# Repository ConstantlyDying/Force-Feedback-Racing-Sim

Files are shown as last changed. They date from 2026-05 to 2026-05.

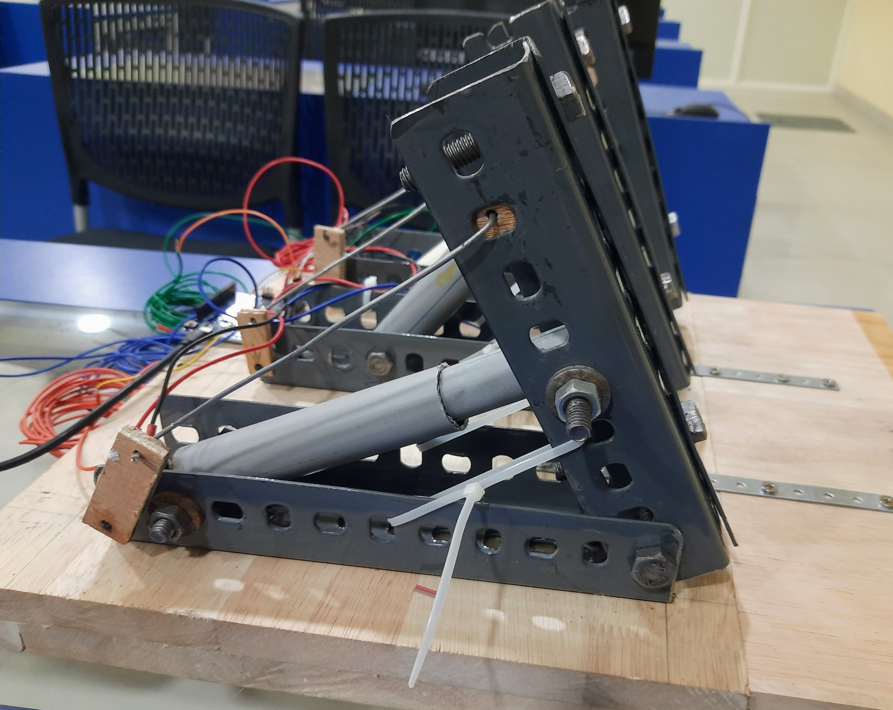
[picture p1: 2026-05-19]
Build Media/Pictures/Pedals/20260518_082918.jpg

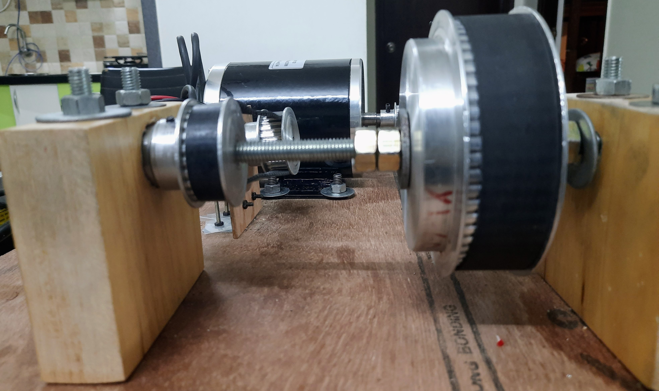
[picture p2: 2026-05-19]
Build Media/Pictures/Wheel Base/20260515_222247.jpg

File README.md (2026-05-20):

# Force-Feedback-Racing-Sim
A budget friendly - DIY Racing simulator, powered by an Arduino Leonardo and a beefy 500w motor!!

FFB Racing Sim2

I made this as a budget friendly alternative to popular sim wheels:), and when your doing this stuff DIY, the possibilities are endless!!, you can literally slap on Wind Sim, Rev Lights, Speedometer, H-shifter, rumble pedals and literally whatever you can think of!!

# Pedals
image_2026-05-05_010524761-Photoroom

These are the pedals. Whenever a certain pedal is pressed; its corresponding potentiometer underoges rotation and sends that analog signal to the Arduino, and communicates with the sim/game.

## -IRL Build


I didn't add the plates as there was enough area on the pedals to apply force onto them without it. You can add the plates if needed though:)

# Wheel-Base
image_2026-05-05_010300429-Photoroom

Pretty straightforward. You rotate the Steering Wheel, the encoder reads the movement and sends it to the Arduino, which communicates it to the sim/game, and sends back a signal to the motor drivers, which induces a movement in the motors accordingly and moves the wheel. There you go, Force Feedback!!

## -IRL Build


I've used one motor driver as that is able to handle my motor load well. You can add one more if you feel the driver is heating up a lot.

# Schematics


FYI: I've custom made the symbols for Arduino, BTS7960, and the Rotary Encoder:)

# Firmware


I've used EMC Lite, which is a popular firmware among the SIM Racing community. Obviously, you can use any other firmware depending on your microcontroller (I'm using an 8bit Arduino Leonardo). This firmware has all the essentials for providing proper Force Feedback, supports 3 pedals, and can handle upto 16 switches with a leonardo. You can definitely add on functionality by using other softwares like SimHub in addition to this for more immersiveness (such as: adding wind sim or rev lights).

# Step-By-Step Build Guide
Yep!! a fully detailed build guide :))



Head to [Detailed Build Guide](https://github.com/ConstantlyDying/Force-Feedback-Racing-Sim/tree/main/Detailed%20Build%20Guide) to access it!

# Demo
https://youtu.be/QV2LuhKqWK8

# BOM
|SR. No: |Name: |Quantity:|Unit Price: (INR) |Total Price:(INR)|Unit Price: (USD) |Total Price:(USD)|Link: |Merchant |Description |
|---|---|---|---|---|---|---|---|---|---|
|STEERING WHEEL:| | | | | | | | | |
| |ELECTRONICS: | | | | | | | | |
|1 |24V 500W 2500RPM MY1020 EBIKE Brush Motor |1 |₹4,400.00 |₹4,400.00 |$46.11 |$46.11 |https://robu.in/product/500w-24v-dc-2500-rpm-for-scooter-bike-go-kart-minibike-e-atv-my1020/ |Self Sourced|A DC motor to drive the wheel |
|2 |Double BTS7960 43A H-Bridge High-Power Stepper Motor Driver|1 |₹300.00 |₹300.00 |$3.14 |$3.14 |https://robu.in/product/double-bts7960-43a-h-bridge-high-power-stepper-motor-driver-module/ |Self Sourced|The motor driver for controlling the motor |
|3 |Arduino Leonardo R3 Board |1 |₹500.00 |₹500.00 |$5.24 |$5.24 |https://robu.in/product/arduino-leonardo-r3-board-micro-usb/ |Self Sourced|Microcontroller for running the firmware and integrating all components|
|4 |1000 PPR AB 2-Phase Optical Rotary Encoder |1 |₹2,500.00 |₹2,500.00 |$26.20 |$26.20 |https://robu.in/product/orange-1000-ppr-ab-phase-incremental-optical-rotary-encoder/ |Self Sourced|Rotary encoder for detecting turns in the steering wheel |
|5 |24VOLT 41AMP 1000WAT SMPS |1 |₹6,000.00 |₹6,000.00 |$62.87 |$62.87 |https://tridevpowersupply.com/product/my-tridev-24volt-41amp-1000wat-switching-power-supply-universal-regulated-transformer-ac-110v-220v-to-dc-24v-41a|Self Sourced|Main power supply to power up everything |
|6 |Cooling fans - 24V |2 |₹150.00 |₹300.00 |$1.57 |$3.14 |https://robu.in/product/a423-fs4020x24v-brushless-dc-cooling-fan-with-2pin-cable-for-3d-printer/ |Self Sourced|Cooling fans to dissipate heat from motor driver |
| |HARDWARE: | | | | | | | | |
|7 |Threaded Metal rod (10mm) |1 |₹150.00 |₹150.00 |$1.57 |$1.57 |Sourced locally |Self Sourced|For the steering shaft |
|8 |Steering Wheel |1 |₹2,500.00 |₹2,500.00 |$26.20 |$26.20 |https://www.amazon.in/AUTO-MT-Tractor-13INCH-Steering/dp/B0B7BLK5XZ/ref=sr_1_2 |Self Sourced|Reduces rpm of motor and provides more torque in a 1:4 ratio |
|9 |big timing pulley (XXL-60teeth) |1 |All pulleys with belt costed 7500| |All pulleys with belt costed $78.80| |Sourced locally |Self Sourced| |
|10 |small timing pulley(XXL-15teeth) |1 | | | | |Sourced locally |Self Sourced| |
|11 |medium timing pulley(XL-22 teeth) |2 | | | | |Sourced locally |Self Sourced|Detects rotation of steering by connecting to encoder in a 1:1 ratio |
|12 |timing belt(XL) |1 | | | | |Sourced locally |Self Sourced|Connects the pulleys |
|13 |timing belt (XXL) |1 | | | | |Sourced locally |Self Sourced| |
|14 |bearings (25mm OD, 10mm ID) |2 |₹150.00 |₹300.00 |$1.57 |$3.14 |Sourced locally |Self Sourced|Helps the motor shaft move more smoothly |
|15 |Nuts (m10) |10 |₹10.00 |₹100.00 |$0.10 |$1.00 |Sourced locally |Self Sourced|For fastening |
|16 |Self drill screws |12 |₹5.00 |₹60.00 |$0.05 |$0.60 |Sourced locally |Self Sourced|For fastening |
|17 |Wood Mount for steering shaft (10*9cm) |2 | | | |$0.00 |Sourced locally |Self Sourced|The shaft goes here along with the bearings |
|18 |Wood Base (40*65cm) |1 | | | |$0.00 |Sourced locally |Self Sourced|Wooden base of the wheel base, for mounting everything |
|19 |Nuts and Bolts (M8) |10 |₹20.00 |₹200.00 |$0.21 |$2.10 |Sourced locally |Self Sourced|for fastening everything |
|PEDALS: | | | | | | | | | |
|20 |10k rotary potentiometer |3 |₹30.00 |₹90.00 |$0.31 |$0.93 |https://robu.in/product/10k-ohm-3pin-15mm-shaft-potentiometer-pack-of-3/ |Self Sourced|For detecting intensity of pedal press |
|21 |spring |3 |₹200.00 |₹600.00 |$2.10 |$6.30 |Sourced locally |Self Sourced|Gives resistance in the pedals |
|22 |Metal L brackets (19cm) |6 |₹150.00 |₹900.00 |$1.57 |$9.42 |Sourced locally |Self Sourced|For a rigid pedal frame |
|23 |Metal L brackets set (22cm) |6 |₹150.00 |₹900.00 |$1.57 |$9.42 |Sourced locally |Self Sourced| |
|24 |Nuts and Bolts (m8) |18 |₹20.00 |₹360.00 |$0.21 |$3.78 |Sourced locally |Self Sourced|To fasten everything |
|25 |Nuts and bolts set (m10) |3 |₹20.00 |₹60.00 |$0.21 |$0.63 |Sourced locally |Self Sourced| |
|26 |Self drill screws |10 |₹5.00 |₹50.00 |$0.05 |$0.50 |Sourced locally |Self Sourced| |
|27 |pvc pipe (3/4inch) |3 |₹10.00 |₹30.00 |$0.10 |$0.30 |Sourced locally |Self Sourced|Springs are housed inside this |
|28 |pvc pipe (1inch) |3 |₹10.00 |₹30.00 |$0.10 |$0.30 |Sourced locally |Self Sourced| |
|29 |Machining Costs |1 |₹600.00 |₹600.00 |$6.29 |$6.29 |Sourced locally |Self Sourced|Machining, such as cutting the wood and metal pieces |
|30 |Wood base (30*36cm) |1 | | | | |Sourced locally |Self Sourced|Wooden Base for mounting the pedals. |

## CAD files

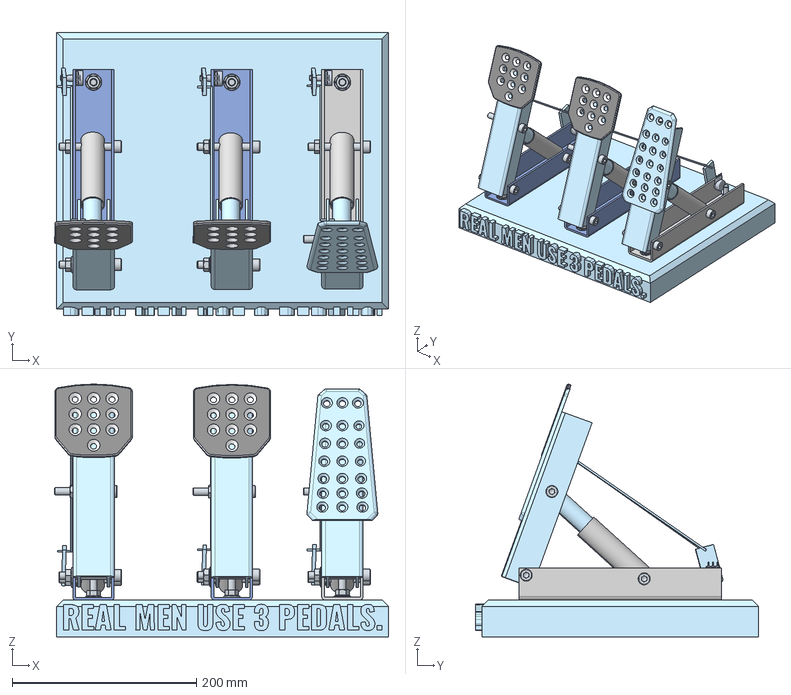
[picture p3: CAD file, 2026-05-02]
CAD (as step file)/Fully Assembled/Pedals/PEDALS MAIN.step
362.3 x 307.0 x 274.3 mm
Hex flange nut M8x1.25 x 15
Surface 1 x 3
Hex socket head cap screw M8x1.25 x 50 x 6
Fanatec_CSP-V3 v8 x 2
Hex socket head cap screw M8x1.25 x 60 x 9
id114 x 3
id119 x 3
id124 x 3
id129 x 3
id134 x 3
id139 x 3
id144 x 3
id149 x 3

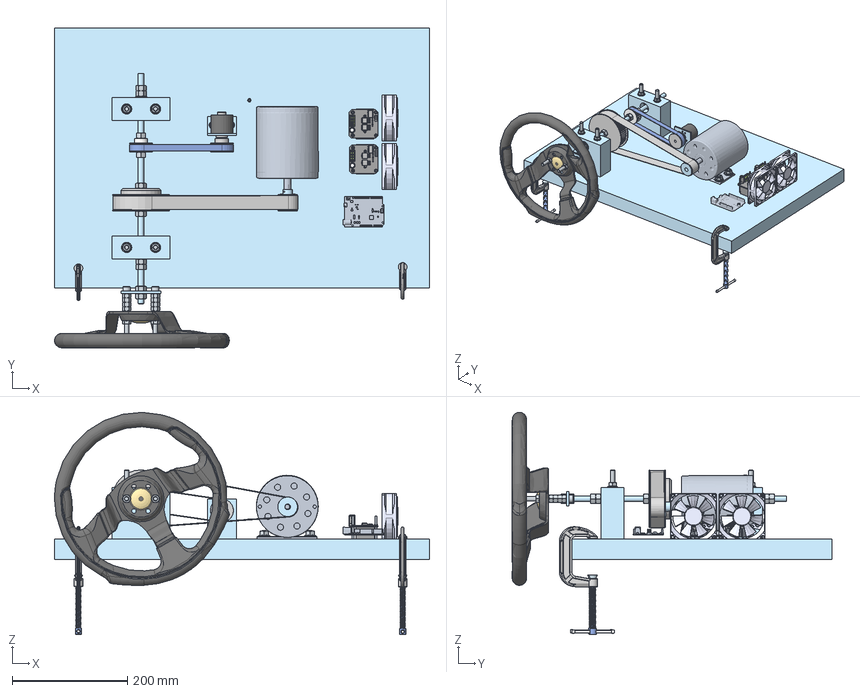
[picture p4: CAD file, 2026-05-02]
CAD (as step file)/Fully Assembled/Wheel Base/WHEEL BASE MAIN.step
650.1 x 554.0 x 385.5 mm
Hex flange nut M10x1.50 x 4
Hex nut grade A & B M3x0.5 x 10
Hex socket head cap screw M6x1.00 x 35 x 2
Fan x 8
4668K121_Permanently Lubricated Stainless Steel Ball Bearing x 10
Hex nut grade A & B M10x1.5 x 10
Hex nut grade A & B M8x1.25 x 12
Hex socket head cap screw M3x0.50 x 60 x 18 x 8
Coil x 20
Spur gear (22 teeth) x 2
Chamfered plain washer normal M10 x 2
id124
id129
id134
ROTARY ENCODER rohit v1 x 2
Hex socket head cap screw M8x1.25 x 140 x 4
Hex flange nut M8x1.25 x 6
Hex socket head cap screw M8x1.25 x 35 x 4
id199 x 2
id204 x 2
id209 x 2
id214 x 2
id219 x 2
id224 x 2
id229 x 2
id234 x 2
id239 x 2
id244 x 2
Fan Body x 2
Hex socket head cap screw M8x1.25 x 80 x 2
id285
Hex flange nut M6x1.00 x 2
steering wheel 300mm
COMBINE2 x 2
CUT-EXTRUDE6 x 2
SOJ 20_001 x 18
2Pos Terminal Block_002 x 10
Capacitor_001 x 16
0805 Resistor_005 x 2
2Pos Terminal Block_001 x 10
2x4 Male Header_001 x 2
M2.5x6-Screw x 4
BTN7960_001 x 2
0805 Resistor_001 x 2
0805 Resistor_002 x 2
0805 Resistor_007 x 2
0805 Resistor_008 x 2
0805 Resistor_004 x 2
0805 Resistor_006 x 2
BTN7960_002 x 2
0805 Resistor_003 x 2
Spur gear (60 teeth)

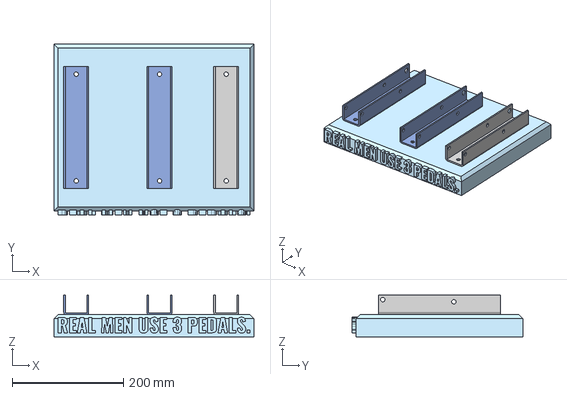
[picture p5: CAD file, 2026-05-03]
CAD (as step file)/Parts/Pedals/pedal base.step
360.0 x 307.0 x 75.0 mm

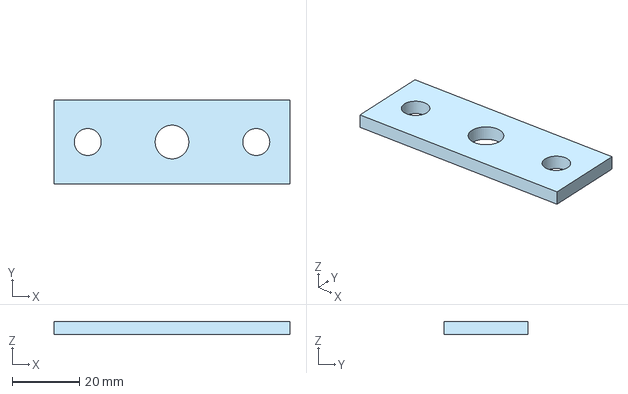
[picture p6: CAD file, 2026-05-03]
CAD (as step file)/Parts/Wheel Base/steering mount.step
70.0 x 25.0 x 4.00 mm

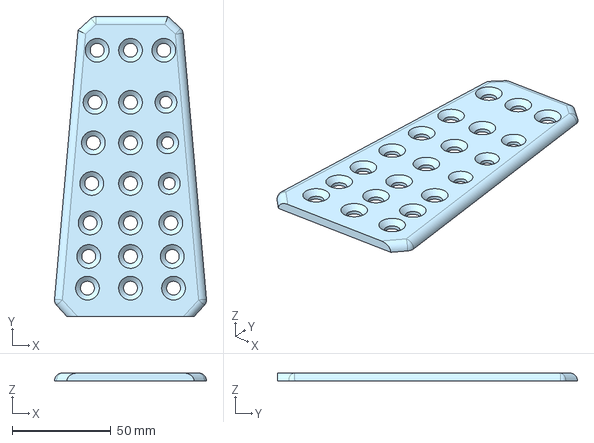
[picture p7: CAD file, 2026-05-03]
CAD (as step file)/Parts/Pedals/Accelerator.step
76.9 x 151.7 x 4.00 mm

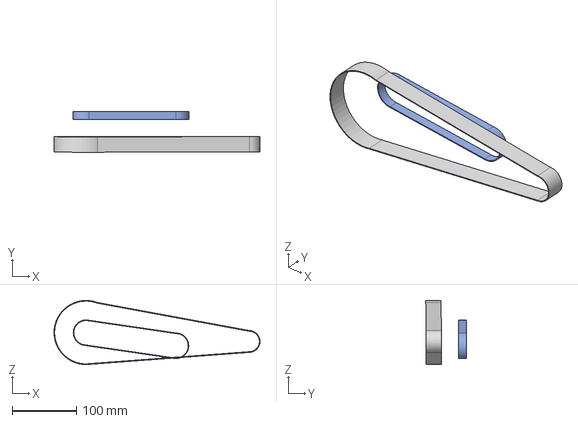
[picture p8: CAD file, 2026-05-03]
CAD (as step file)/Parts/Wheel Base/wheel base.step
321.2 x 63.2 x 100.2 mm

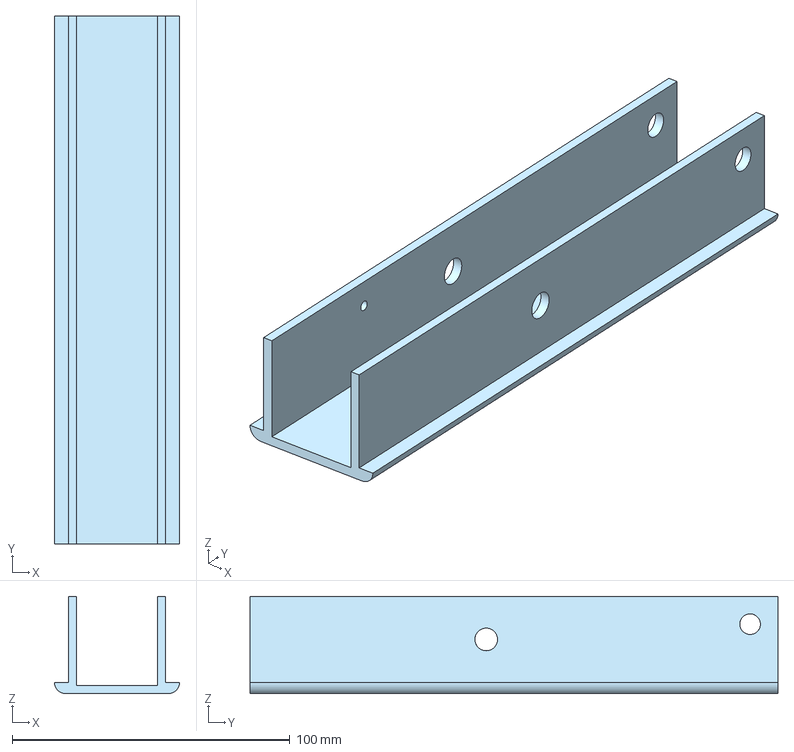
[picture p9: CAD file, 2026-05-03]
CAD (as step file)/Parts/Pedals/upper pedal.step
45.0 x 190.0 x 35.0 mm

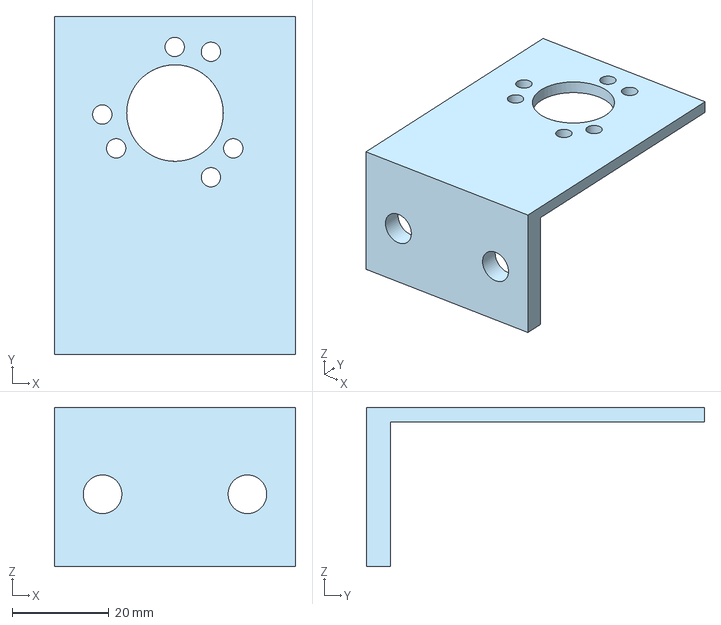
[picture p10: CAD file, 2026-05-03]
CAD (as step file)/Parts/Wheel Base/encoder mount.step
50.0 x 70.0 x 33.0 mm

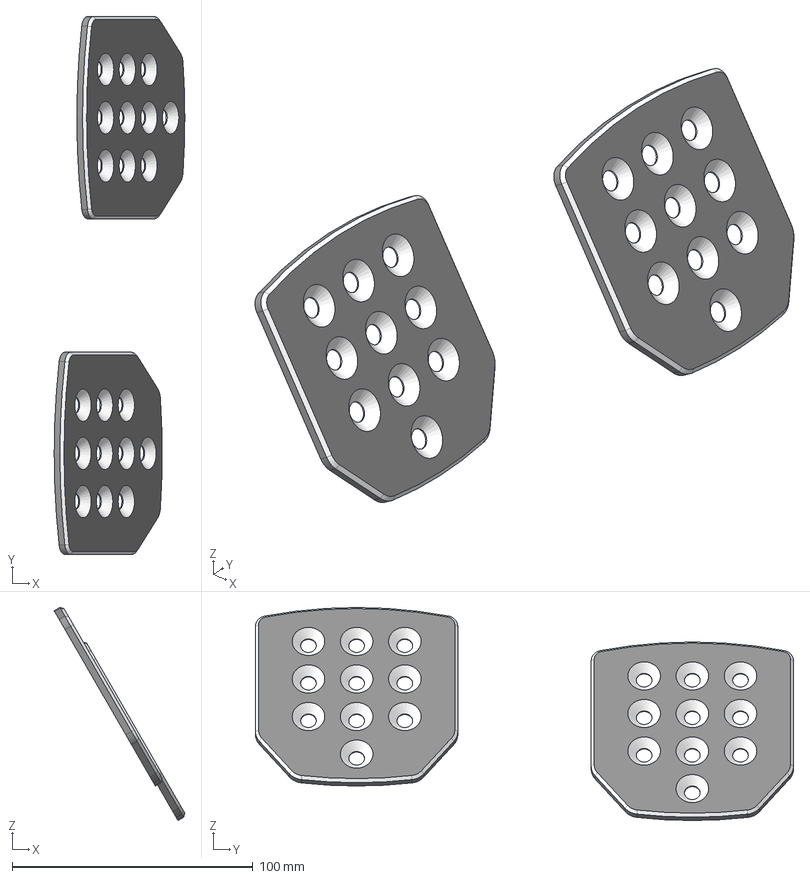
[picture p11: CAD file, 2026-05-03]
CAD (as step file)/Parts/Pedals/pedal plates.step
54.2 x 223.4 x 88.5 mm
Fanatec_CSP-V3 v8 x 2

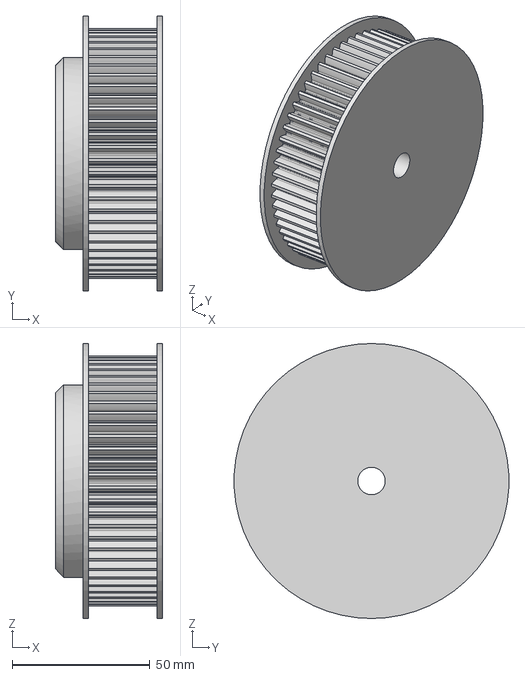
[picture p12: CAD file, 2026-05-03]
CAD (as step file)/Parts/Wheel Base/60 teeth pulley.step
39.0 x 99.9 x 100.0 mm

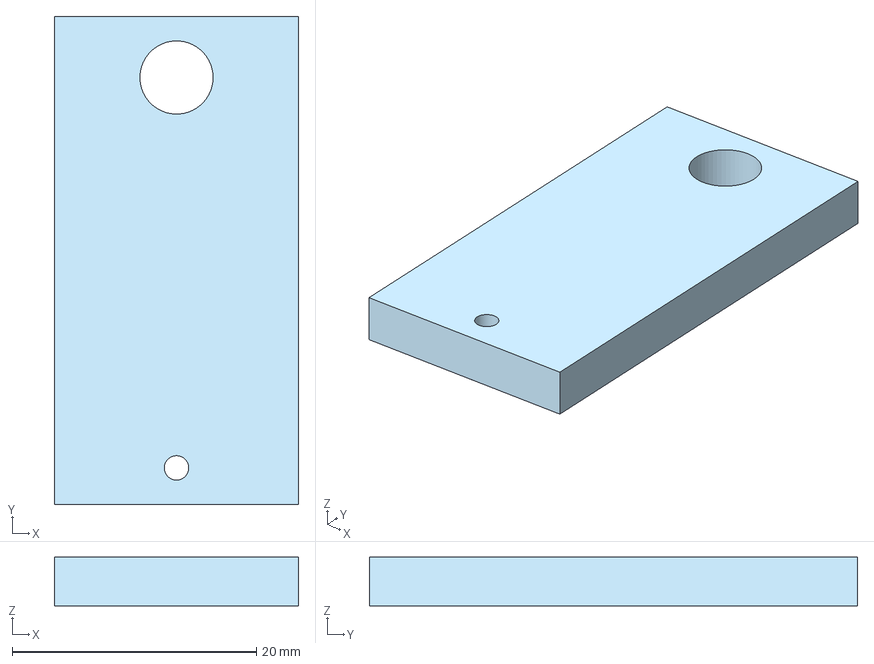
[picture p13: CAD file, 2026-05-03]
CAD (as step file)/Parts/Pedals/wooden rectangle.step
20.0 x 40.0 x 4.00 mm

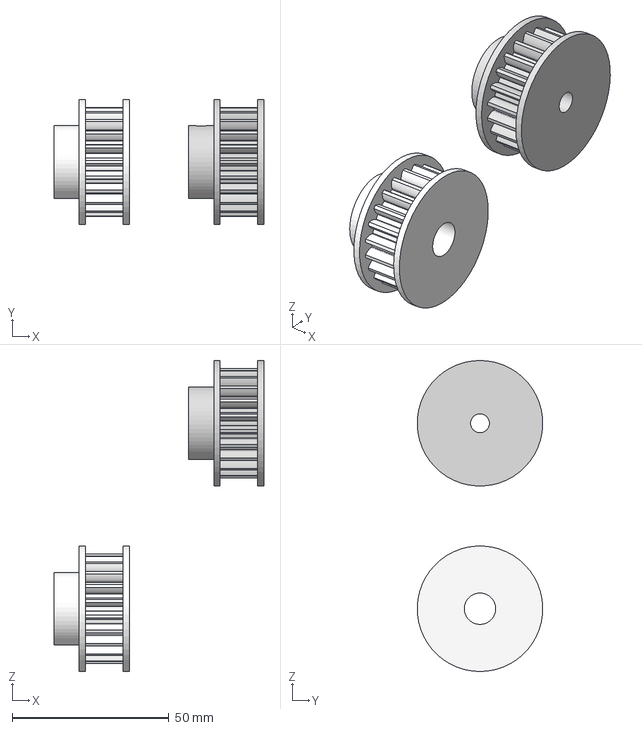
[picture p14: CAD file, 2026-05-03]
CAD (as step file)/Parts/Wheel Base/22 teeth pulleys.step
66.9 x 40.0 x 99.1 mm

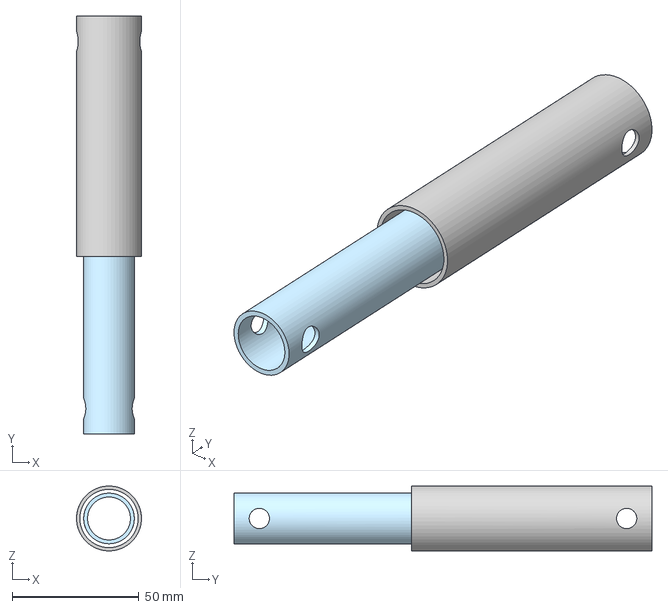
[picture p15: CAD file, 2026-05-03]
CAD (as step file)/Parts/Pedals/pipes.step
25.6 x 165.0 x 25.6 mm

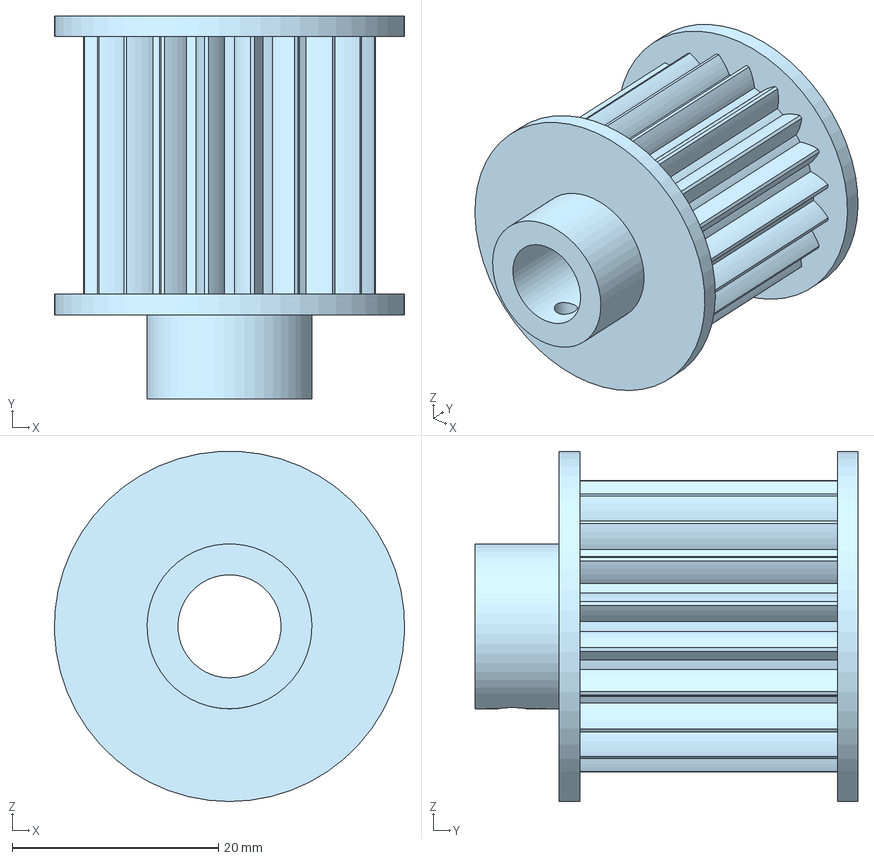
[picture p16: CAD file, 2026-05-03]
CAD (as step file)/Parts/Wheel Base/Motor pulley.step
34.0 x 37.2 x 34.0 mm

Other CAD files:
CAD (as step file)/Parts/Pedals/push rod.step
CAD (as step file)/Parts/Wheel Base/bearings.step
CAD (as step file)/Parts/Pedals/potentiometer.step
CAD (as step file)/Parts/Wheel Base/threaded rod.step

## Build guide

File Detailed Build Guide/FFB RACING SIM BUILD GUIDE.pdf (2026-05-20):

## FFB RACING SIM -BUILD GUIDE:

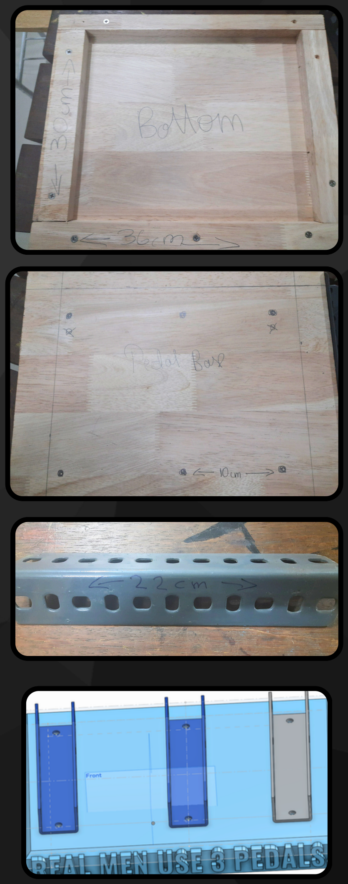
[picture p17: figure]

## PEDALS:

Get your wooden base of dimension 36cm by 30cm (if you are
anchoring it somewhere), or 36cm by 45cm if you are not anchoring it.
Add 4 beams of about 3cm width to each edge.
With the help of 22cm L-Bracket, mark 3 sets oh holes on the base for each pedal. (10cm b/w the brake and gas pedal ; 17cm b/w the brake and the clutch).
Now drill the holes with an 8mm drill bit.
Take 2 of the 22cm L-Brackets and overlap them, to for a U-Shape, now mount them on the base with m8 nuts and bolts.
Repeat the previous step thrice.

## NOTE:

This is just a guide, you are free to change the dimensions or components if you like, provided you know what you are doing.
Every step does not need to be exact, a close enough replication works, as lot of the stuff I used were sourced locally:)

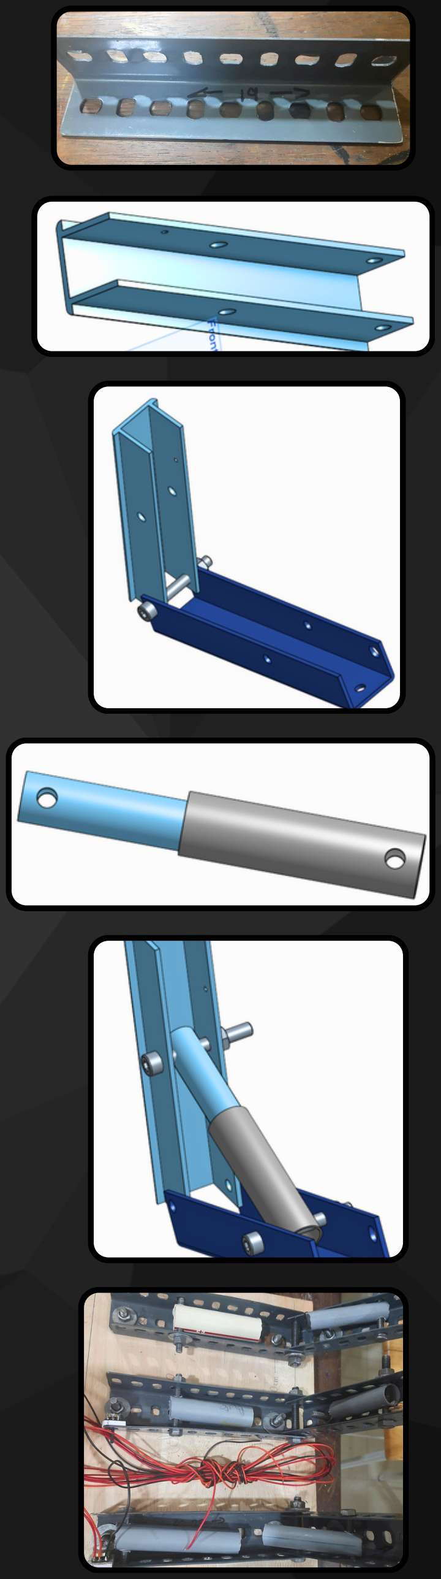
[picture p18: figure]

Take 2 of the 19cm L-Brackets and overlap them to form a U-shape and fasten them together with m8 nuts and bolts.
Now join the upper pedal to the base with m10 nuts and bolts. You can use a pair of pliers to bend the base L-Bracket outwards if needed.
Take out your ¾ inch and 1 inch pvc pipes and cut them to 10cm each(3pcs for each dia), this length depends on your spring, I am using a 4inch one. It also depends on how much pressure you want to apply on the pedals, so definitely feel free to
customize.
Now drill out one hole through each pipe with an 8mm drill bit. Now take the 1inch pipes and mount them to the base L-Bracket with m8 nuts and bolts, and do the same for the ¾ inch pipes, but to the upper pedal.
Repeat this step thrice.
Now use epoxy to make a seal on the other end of each ¾ inch pipe.
Once that dries, take out your spring and put it in the 1inch pipe.
Now use the ¾ inch pipe to enclose the spring, and use zipties or something to limit the pedals movement so the springs don’t come out.

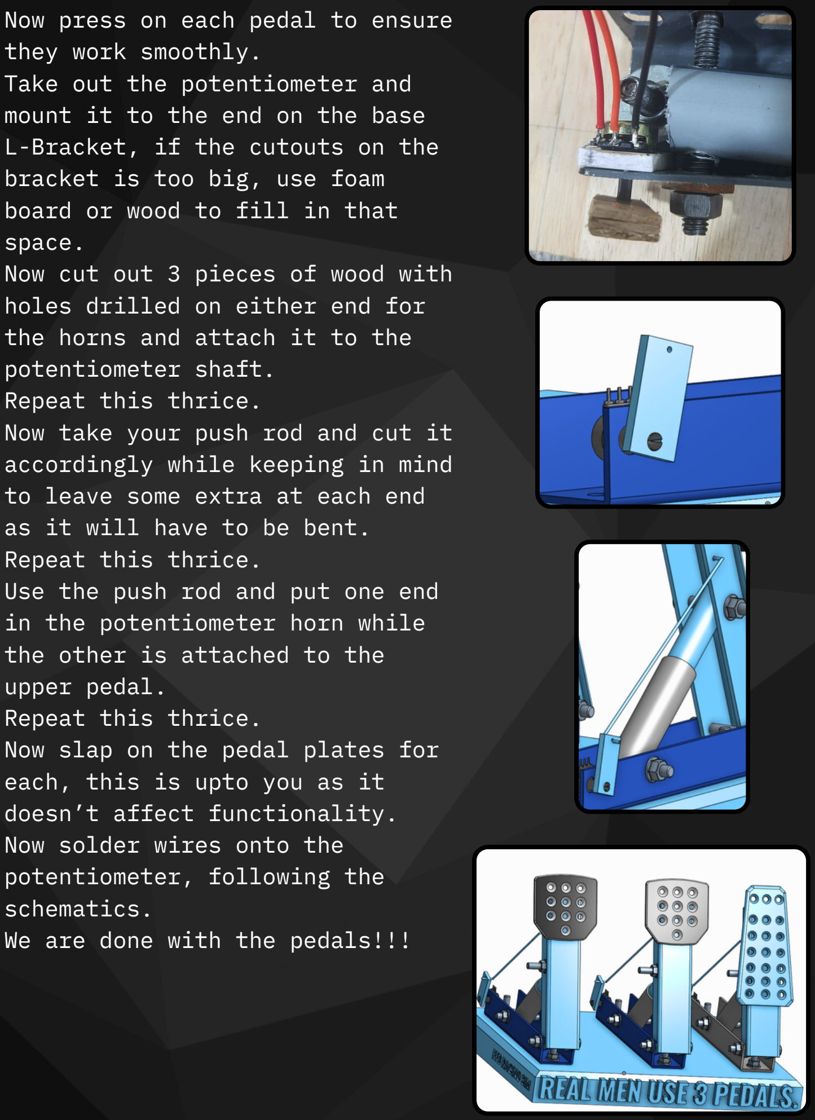
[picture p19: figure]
Now press on each pedal to ensure they work smoothly. Take out the potentiometer and mount it to the end on the base L-Bracket, if the cutouts on the bracket is too big, use foam board or wood to fill in that space. Now cut out 3 pieces of wood with holes drilled on either end for the horns and attach it to the potentiometer shaft. Repeat this thrice. Now take your push rod and cut it accordingly while keeping in mind to leave some extra at each end as it will have to be bent. Repeat this thrice. Use the push rod and put one end in the potentiometer horn while the other is attached to the up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

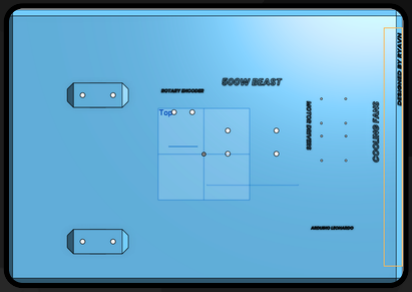
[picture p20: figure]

## Wheel-base:

Take a wooden base of dimension 40cm*65cm
Take the wooden steering shaft mount of dimensions 9*10cm with the bearing mounted in it.
Drill 2 holes in the wooden mount through out with an 8mm drill bit.
Now with the help of the
steering shaft mount, mark 2 holes about 7 to 8cm away from the long edge (please refer to the onshape link or cad file for a better understanding).
Now with the help of the same mount, mark 2 more holes about 24 to 25cm away from the previous holes.
Now drill these holes with an 8mm drill bit.
Mount one steering shaft mount to the holes closer to the edge with m8 nuts and bolts.
Now insert the threaded rod into the bearing and position the 2 steering shaft mount on the other set of holes, but don’t mount it yet.

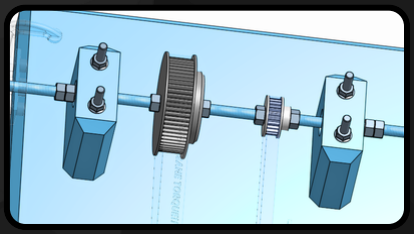
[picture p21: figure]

nd

Now Take out the 60 teeth and 22 teeth pulleys and fasten them to the threaded rod as shown in the CAD. Ensure they are properly secured with m10 bolts.

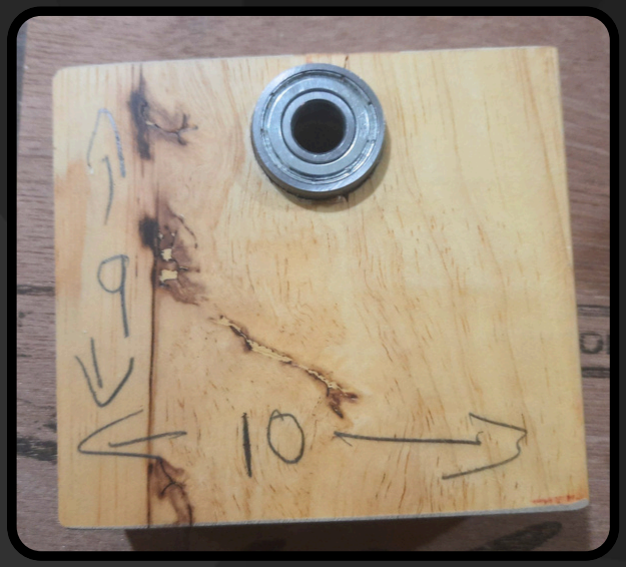
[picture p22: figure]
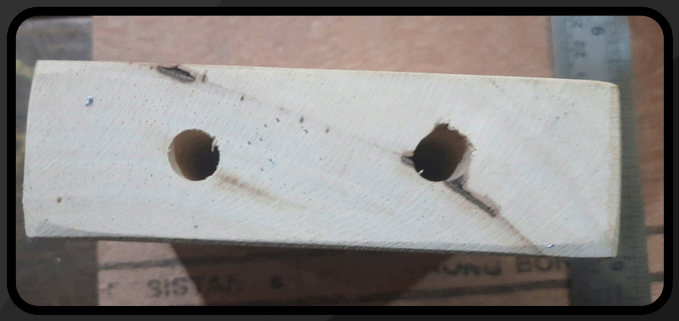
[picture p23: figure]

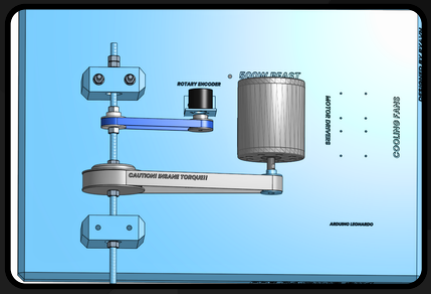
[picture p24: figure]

Now insert both the pulleys’ belts onto the rod.
Mount the other steering shaft mount with m8 nuts and bolts. Take out your motor and encoder (with mount).
Mount the 15teeth pulley onto the motor shaft.
Use the longer timing belt by positioning it on the 60 and 20 teeth pulleys and mark 4 holes for mounting the motor (ensuring the belt is tight and fits snug on the pulleys), ensure these holes are offset to the direction away from the threaded rod by about 0.5cm to induce tension in the belt.
Do the same with the rotary encoder and mark 2 holes.
Now drill out all these holes with an 8mm drill bit.
Mount the rotary encoder and motor to their mount holes accordingly with m8 nuts and bolts.
If the belt doesn’t have enough tension, or is too tight (please refer to yt tutorial on checking belt tension), shift the
corresponding pulley a bit on the threaded rod, and drill the mount holes again, but a bit closer to the shaft.
Now make the steering mount, I used a rectangular metal piece and drilled 3 holes: one 10mm one in the center and

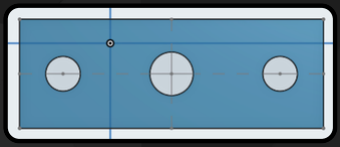
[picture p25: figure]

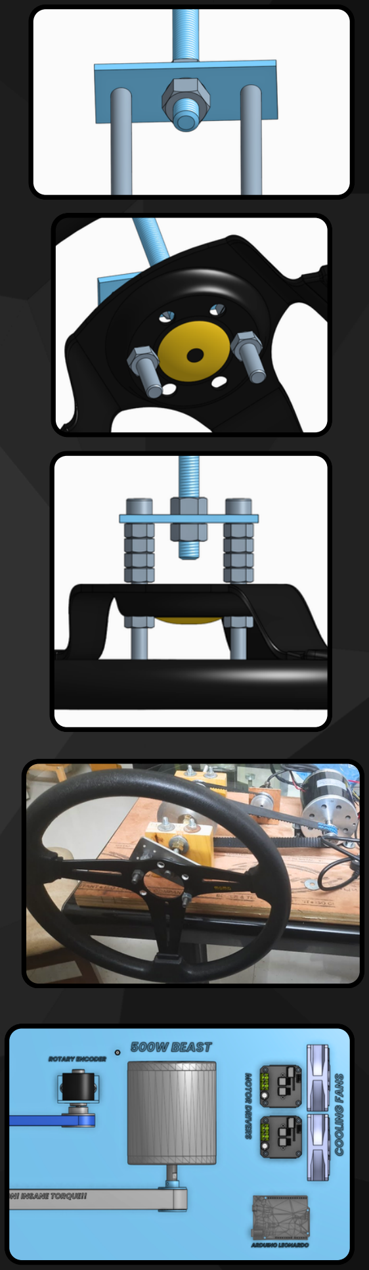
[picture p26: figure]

Now make the steering mount, I used a rectangular metal piece and drilled 3 holes: one 10mm one in the center and two 8mm ones equidistant from the center on both the sides (This depends on your steering wheel).
Now push the center hole onto the steering shaft (threaded rod) and use m10 nuts on either side to fasten it.
Insert two m8 bolts and use a few nuts to act as spacers.
Now mount your steering wheel onto these two m8 bolts and fasten it with m8 nuts.
Give the wheel a spin to check if it moves smoothly:)
Now take both of your motor drivers and position it near the motor.
Now mark out the mount holes for the motor driver, and drill them out with a 4mm drill bit
Mount them with m4 nuts and bolts.
Now take the cooling fans and position it near the heatsinks of the motor driver, you can now glue them in place or use L-Brackets to mount them
accordingly.
Now take your Arduino Leonardo and position it a bit below the motor driver and mark out 4 holes.
Drill the holes with a 4mm drill bit and mount in with a set of m4 nusts

Drill the holes with a 4mm drill bit and mount it with m4 nuts and bolts. You can also use glue! The position of the Arduino, Motor driver and the cooling fans aren’t that crucial, as long as the wiring is neat and they have proper ventilation:)
Now wire them up according to the schematics.
You have officially finished the Wheel Base!!!

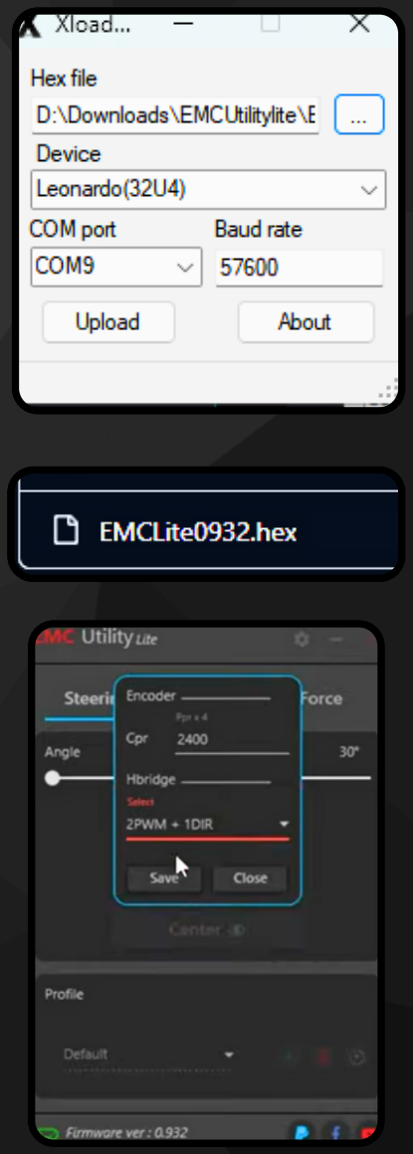
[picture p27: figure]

## Configuring:

Download all the required files from my GitHub Repo.
Connect your Arduino to your PC, and open Xloader.
Select the downloaded hex file from my repo, leonardo as the device.
Now short the reset and GND pins briefly on the leonardo and remove, this will show a new COM port, which you have to select. Now upload the firmware.
Now open settings, and set the cpr value to your ppr value*4, mine is 1000 so cpr = 4000 and save it.
Now go to the pedals tab for calibration: Keep a pedal pressed down entirely, and click max; now let go of it and click min. Repeat this thrice.

Download all the required files from my GitHub Repo.
Connect your Arduino to your PC, and open Xloader.
Select the downloaded hex file from my repo, leonardo as the device.
Now short the reset and GND pins briefly on the leonardo and remove, this will show a new COM port, which you have to select. Now upload the firmware.
Now open settings, and set the cpr value to your ppr value*4, mine is 1000 so cpr = 4000 and save it.
Now go to the pedals tab for calibration: Keep a pedal pressed down entirely, and click max; now let go of it and click min. Repeat this thrice.
Now go to the main page, now center your steering wheel physically and click center wheel.
You can set the max degree of rotation for the steering wheel depending on your game/sim.
You can also go to the force tab and play around with the
settings, till you find it comfortable.

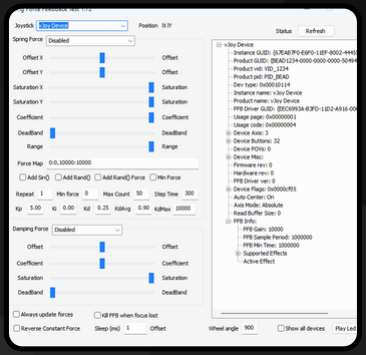
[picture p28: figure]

You must always keep the EMC app open when running the wheel. Select EMC for joystick.
You can use the Wheel Check software to test if the wheel is running smoothly.
You can open any compatible game/sim and connect the
controller like any other
wheel:).
Calibrate all the axes and buttons and you’re good to go!! You’ve officially completed the build!!!!

## Testing:

# -BY Ryaan Ahmed:)

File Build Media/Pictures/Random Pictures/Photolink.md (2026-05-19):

https://photos.app.goo.gl/hW5AqJL3e2coWAPn7

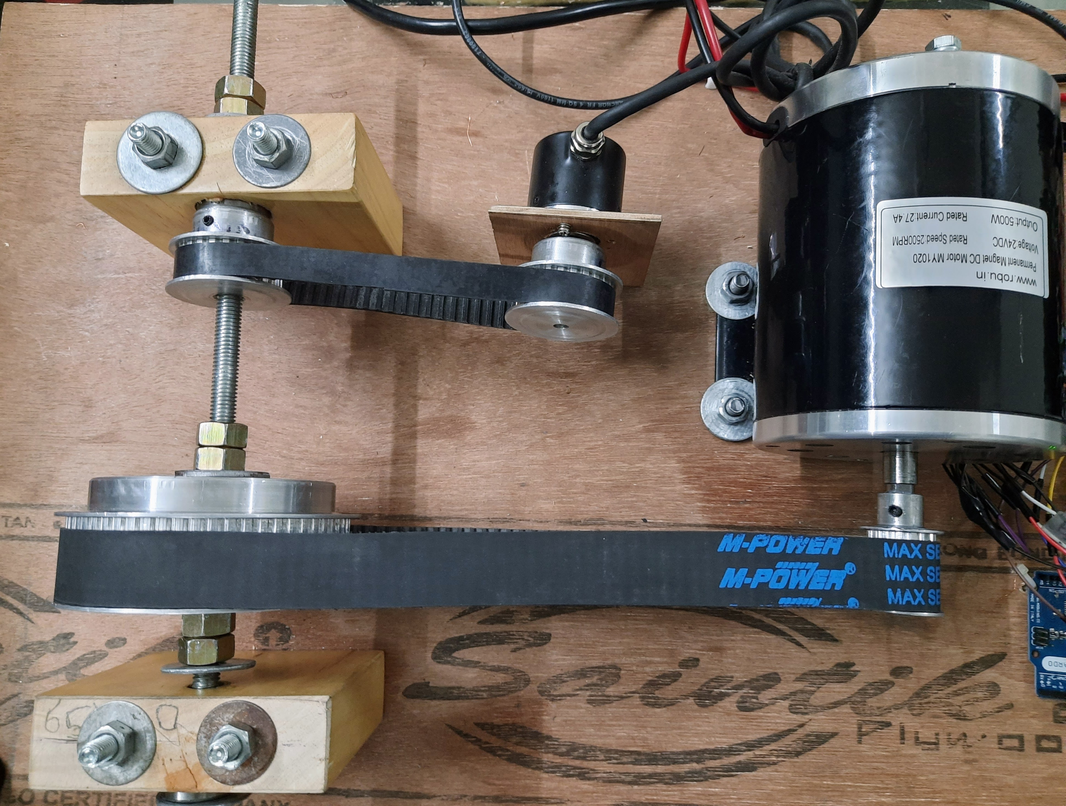
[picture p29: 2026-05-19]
Build Media/Pictures/Wheel Base/20260515_222138.jpg

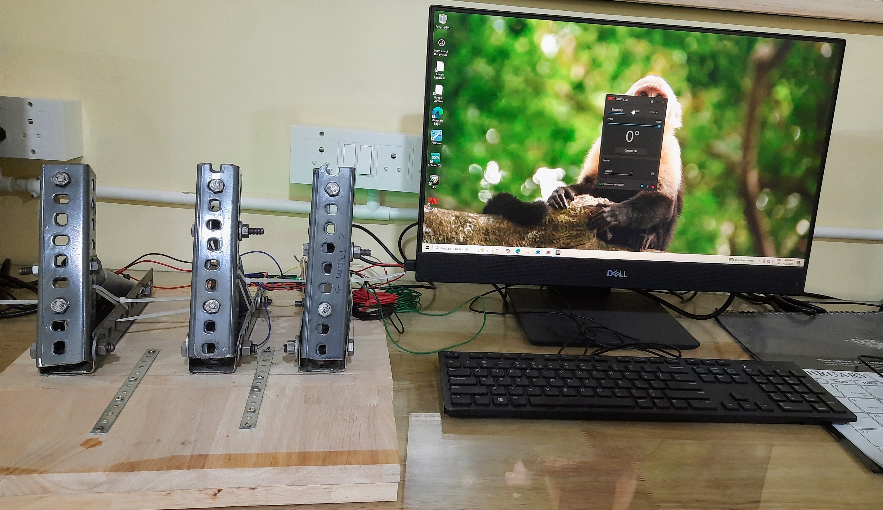
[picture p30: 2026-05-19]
Build Media/Pictures/Pedals/20260518_082357.jpg

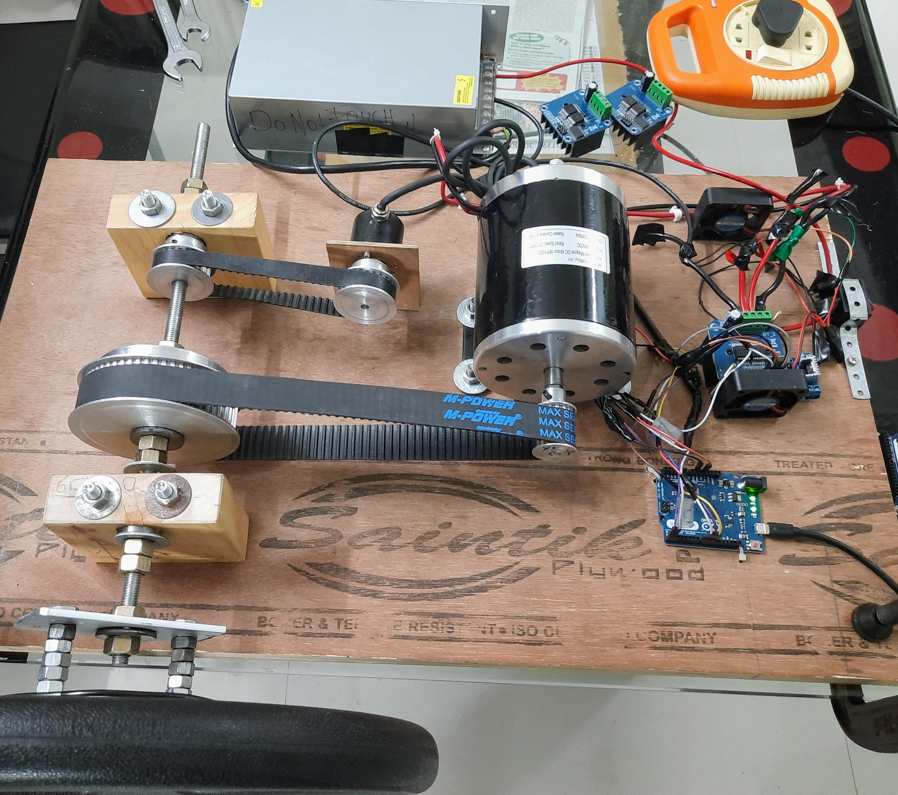
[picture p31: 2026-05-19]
Build Media/Pictures/Wheel Base/20260515_222124.jpg

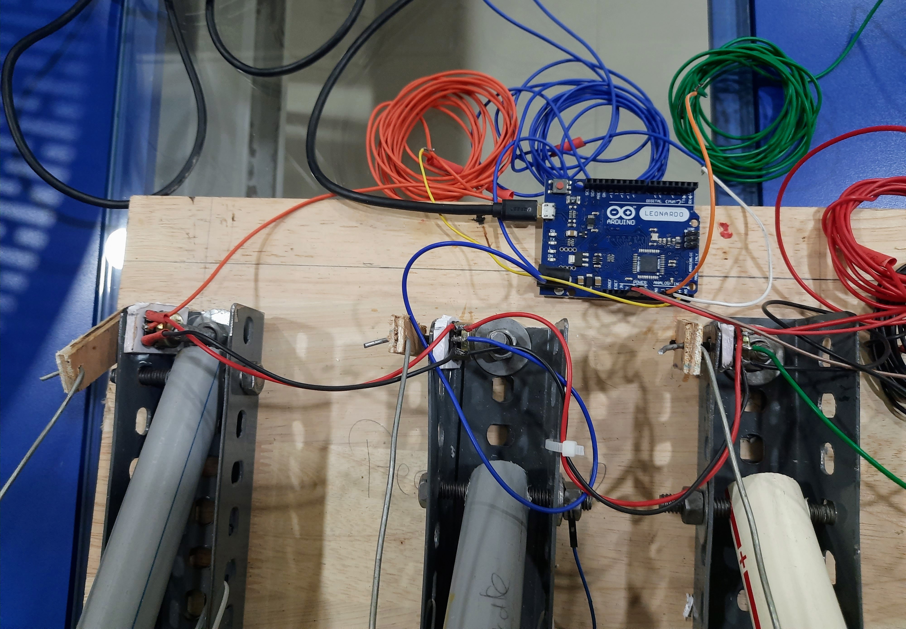
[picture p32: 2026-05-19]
Build Media/Pictures/Pedals/20260518_082927.jpg

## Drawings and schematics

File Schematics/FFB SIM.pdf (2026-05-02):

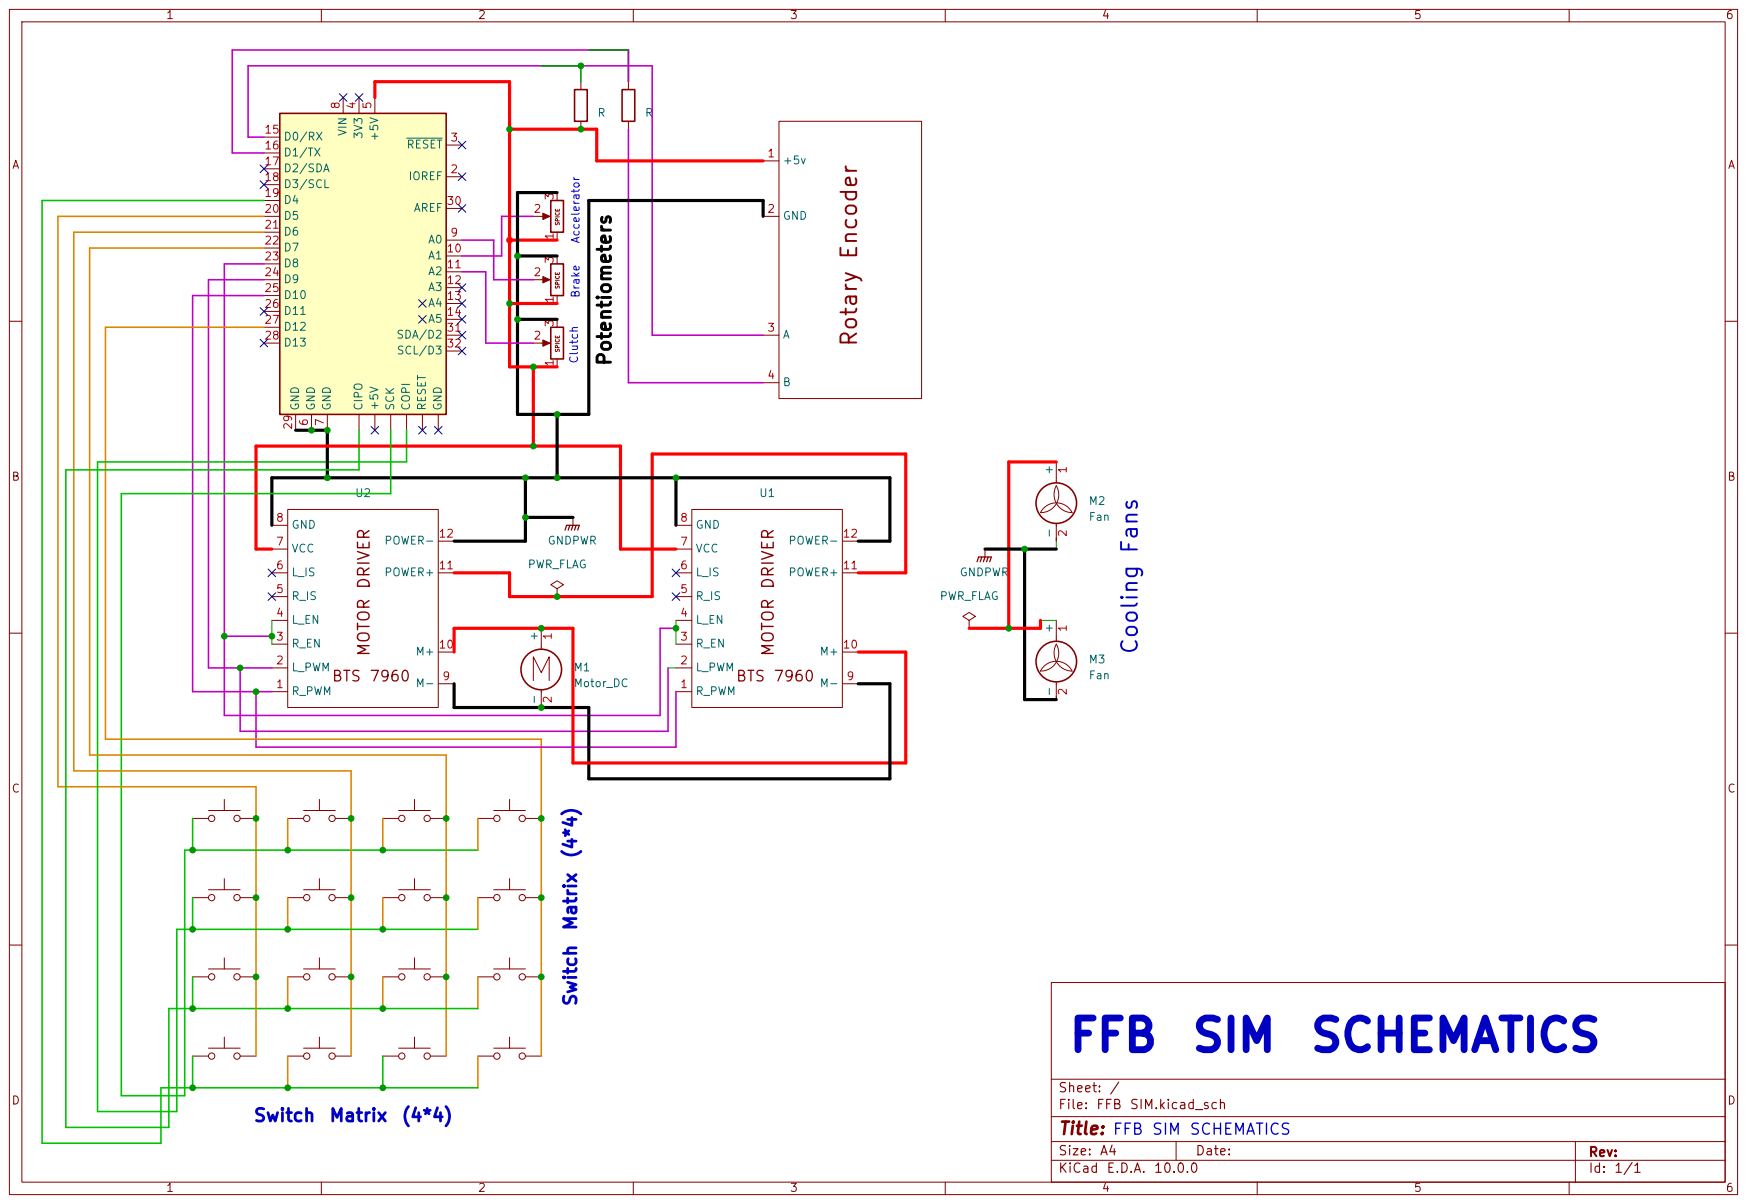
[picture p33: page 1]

Size: A4 | Rev:
KiCad E.D.A. 10.0.0 | Id: 1/1

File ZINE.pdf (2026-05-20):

FORCE | FEEDBACK
RACING | SIM

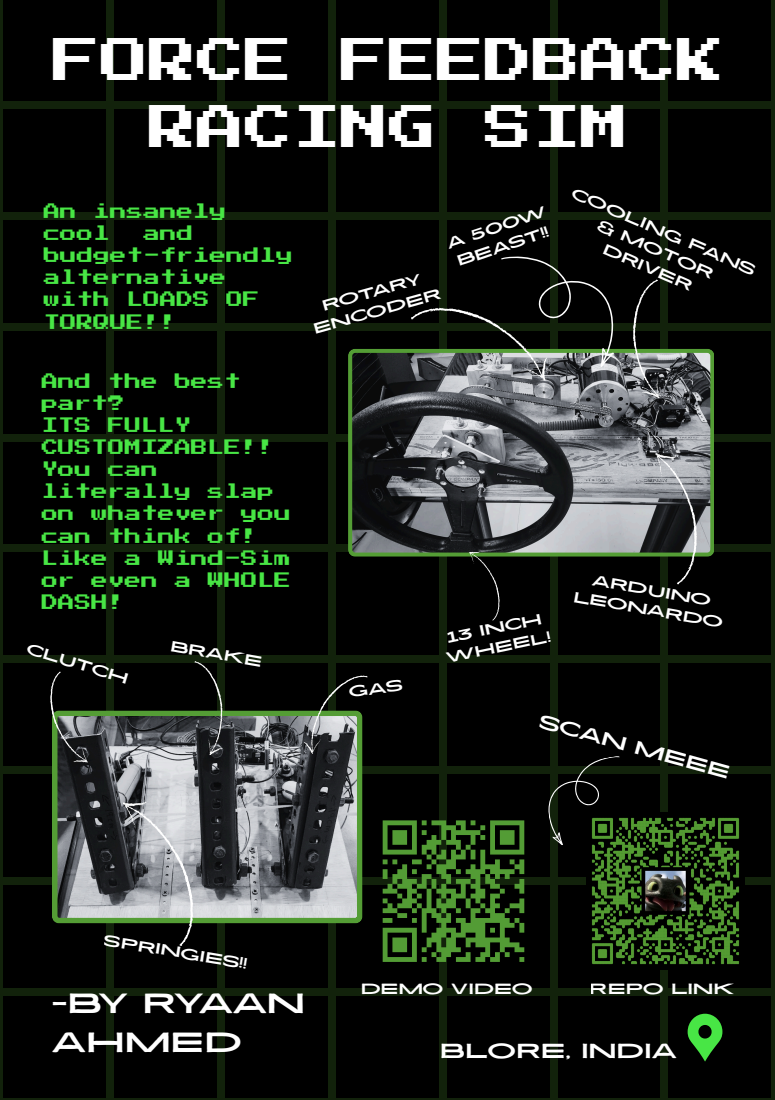
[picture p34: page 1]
13 inch wHEEL!; SpRINGIES!!; A 500W BEAST!!; duino; ARDO; ROTARY ENCODER; COOLING FANS & Motor dRIVER; GaS; BrAKE CLuTCH; An insanely; cool; and; budget-friendly alternative; with; LOADS; TORQUE!!; And; the best; ITS; FULLY; You; can; on whatever; you; think of!; Like; a Wind-Sim; SCAN MeEE; DEMO; VID; LINK; yaan; hMED; bLORE, INDIA

part?
CUSTOMIZABLE!!
literally slap
or even a WHOLE
DASH!

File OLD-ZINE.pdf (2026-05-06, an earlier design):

FORCE | FEEDBACK
RACING | SIM

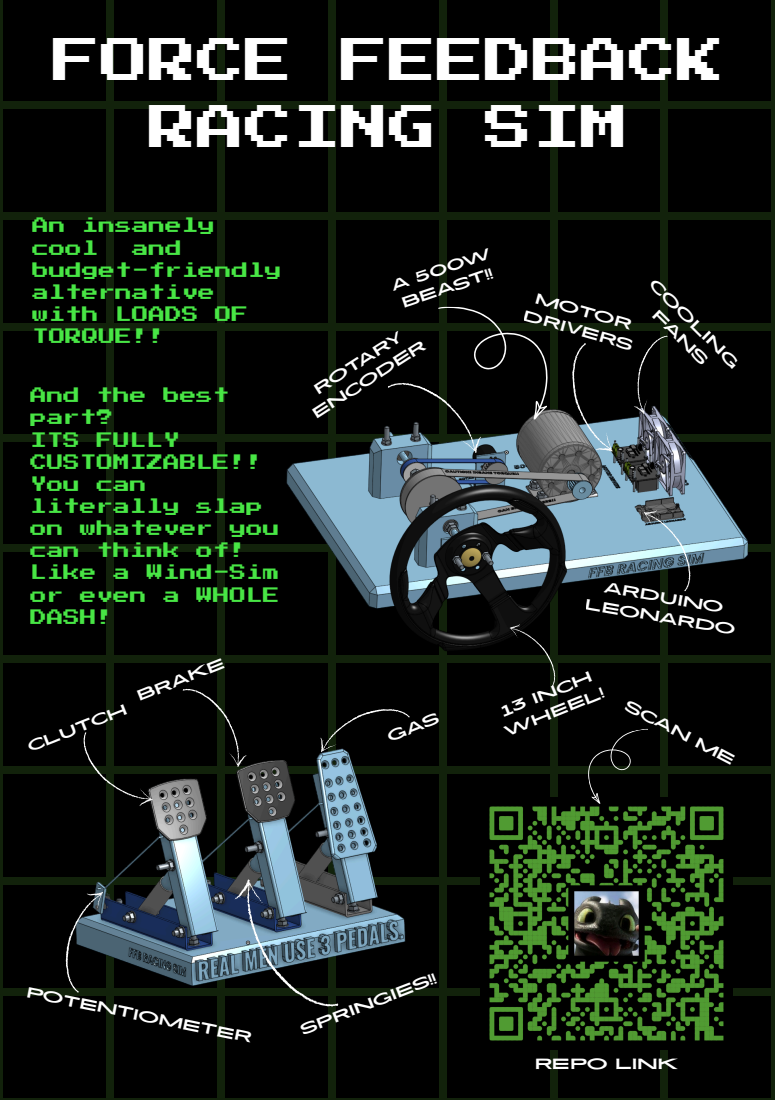
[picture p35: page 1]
13 inch; wHEEL!; A 500W BEAST!!; duino; ARDO; ROTARY ENCODER; COOLING FANS; TOR ERS; GaS; BrAKE; CLuTCH; pOTENTIOMETER; SpRINGIES!!; An insanely; cool; and; budget-friendly alternative; with; LOADS; SCAN ME

TORQUE!! And the best part?

ITS FULLY
CUSTOMIZABLE!! You can literally slap on whatever | you

can think of!
Like or even a WHOLE DASH! | a Wind-Sim

PO LINK

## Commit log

2026-05-02 Add files via upload
    Xloader.exe file for uploading firmware to Arduino
2026-05-04 Create Onshape Source file (CAD)
